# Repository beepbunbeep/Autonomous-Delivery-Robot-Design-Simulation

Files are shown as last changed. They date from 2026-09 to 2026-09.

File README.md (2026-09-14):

Hello!
Added here are all the files related to my autonomous delivery robot project. I designed the full robot architecture in SolidWorks after calculating needed strength under the planned load with a safety factor of 1,5.
Then, I developed MATLAB/Simulink models for kinematic and dynamic analysis, trajectory tracking and control-system evaluation. I dimensioned each of the three motors under simulated load and overload conditions and selected appropriate models. 

The design is fully functional, all is calculated and tested in MATLAB/SIMULINK Multibody.

The battery, driving, steering and drawer actuation motors have all be dimensioned and selected. These can be found in the provided documentation.

The documentation is currently only in Macedonian, as I made this for one of my classes however I will work on providing an English version for wider accessibility. 

I am making these publicly available because I value such repositories when I find them, and it is my great honor to be able to contribute to the engineering community. 
However I humbly ask that you do not use these to cheat on your own classes or pass this project off as your own.

I am not affiliated in any way with the Snoopy brand and have only used Snoopy's likeness to make this project more visually compelling (cuter). No profit has been or will be generated. 

***KEEP IN MIND THAT THERE MAY BE SOME INCONSISTENCIES BETWEEN THE PROJECT FILES AND DOCUMENTATION BECAUSE OF A MISHAP WITH THE VERSION SAVES. THE MAIN PARTS ARE GOOD BUT DETAILS NEED TO BE IRONED OUT.***

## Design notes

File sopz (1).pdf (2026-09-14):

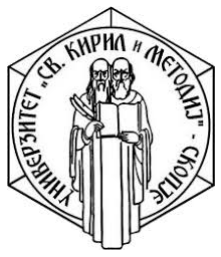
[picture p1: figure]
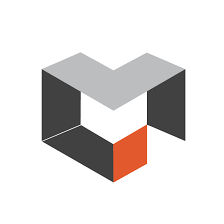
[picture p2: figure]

Универзитет Св. Кирил и Методиj Машински Факултет Скопjе

Семинарска задача по предметот: Механика на роботи

# Дизаjн и симулациjа на АУВ робот за достава

Изработено од: Аника Абдулаху 3132

Ментори: Доц. д-р. Маjа Аначкова Доц. д-р. Деjан Шишковски

## Содржина

1 Вовед | 2
2 Барања на роботот | 3
3 Модел во SolidWorks | 4
4 Сензори и актуатори | 5
5 Симулациjа | 10
6 Заклучок | 15

Абстракт
Во овоj проект е развиен и верификуван концепт на автономен доставен робот AGV со автоматски отварачки товарен отсек и приjатен дизаjн. Механичкиот модел е изработен во SolidWorks, вклучуваj´ки шасиjа, погонски систем и механизам за отворање на отсекот, при што се земени предвид производствени и монтажни ограничувања. Моделот е интегриран во Simulink за спроведување на кинематичка и динамичка анализа, планирање на траекториjа и развоj на контролни алгоритми за прецизно следење и безбедно ослободување на товарот. Симулациите ги оценуваат перформансите во различни работни сценариjа, вклучуваj´ки вариjации на оптоварување, нарушувања и ограничувања на актуаторите. Резултатите покажуваат дека предложениот дизаjн и контролна стратегиjа обезбедуваат стабилно и прецизно следење на траекториjата, сигурно функционирање на механизмот за отворање и добра прифатливост за корисникот во урбани средини. Проектот jа демонстрира ефикасната интеграциjа на CAD дизаjнот и системската симулациjа како основа за понатамошна оптимизациjа и експериментална реализациjа.

## 1 Вовед

Во овоj проект е дизаjниран и симулиран автономен доставен робот со товарен отсек коj автоматски се отвора и со внимателно осмислен естетски дизаjн. Процесот започна со прецизно тридимензионално моделирање во SolidWorks, каде што беа дефинирани конструктивните елементи, споjките и механичките ограничувања на шасиjата, погонскиот систем и механизмот за отворање на отсекот. Моделот потоа беше интегриран во Simulink за да се извршат детални кинематички и динамички анализи, со цел да се проценат положбите, брзините, забрзувањата, како и силите и моментите кои влиjаат на перформансите.
Проектот има за цел да демонстрира методолошка интеграциjа поме´гу CAD дизаjнот и системската симулациjа. Во Simulink беа спроведени студии на траекториjа и модели на динамика за да се верификуваат теоретските предвидувања и да се идентификуваат критичните параметри за стабилност и прецизност. За контролата беа развиени и тестиранe регулатори и "feedforward"стратегии за следење на зададените траектории, при што се анализираше временскиот одговор, грешката при следење и отпорноста на нарушувања. Резултатите обезбедуваат солидна основа за понатамошна оптимизациjа и експериментална валидациjа.
Практичниот фокус на проектот е да се добие инженерски изводлив и оперативен AGV коj може да се пренесе од виртуелна симулациjа во прототип. Во SolidWorks дизаjнот е оптимизиран за монтажа и производствени ограничувања, додека во Simulink се симулираа реални работни сценариjа: различни патеки, оптоварувања, нарушувања и ограничувања на актуаторите. Механизмот за автоматско отворање на товарниот отсек е дизаjниран и контролно интегриран така што обезбедува безбедно и прецизно ослободување на товарот, а естетскиот дизаjн jа подобрува прифатливоста за корисникот во урбани средини.
Комбинациjата на SolidWorks за прецизен механички дизаjн и Simulink за кинематичка, динамичка и контролна симулациjа овозможи целосен инженерски работен тек од концепт до верификациjа. Овоj пристап значително jа намалува неизвесноста пред изработка на физички прототип и дава конкретни препораки за материjали, димензии на погонските елементи и параметри на контролата, како и следни чекори за тестирање и индустриска имплементациjа.

## 2 Барања на роботот

За успешна реализациjа на проектот за автономен доставен робот AGV со автоматски отварачки товарен отсек беа дефинирани следниве барања, класифицирани на механички, функционални, симулациски и ергономски барања.

Механички δарања:

- Робустна и компактна шасиjа, оптимизирана за урбани средини, коjа одговара на формата на пове´ке разни предмети.
- Механизам за автоматско отворање и затворање на товарниот отсек, со сигурно и прецизно функционирање.
- Лесна конструкциjа за намалување на потрошувачката на енергиjа.
- Оптимизациjа на материjали и димензии за практична изработка.

Функционални δарања:

- Решавање на проблемот на „последните три метри“: роботот мора да може да доставува директно до врата на потрошувачите, без потреба трговците да излегуваат надвор или да одат тротуар подолу. [1]
- Автономно движење по зададени траектории со висока прецизност.
- Систем за избегнување пречки и адаптациjа на патеката.
- Контролна логика за управување со траекториjа, брзина и стабилност.
- Функционирање во тристрана пазарна динамика: трговци кои бараат брза и сигурна предавање на производи, потрошувачи со различни преференции за начинот на достава, роботот како посредник коj ги поврзува двете страни.

Симулациски δарања:

- Кинематичка анализа за проверка на положби, брзини и ограничувања.
- Динамичка анализа за проценка на сили, моменти и инерциjални ефекти.
- Тестирање на контролни алгоритми во различни сценариjа (оптоварувања, нарушувања).

Есшешски и ерıономски δарања:

- Дизаjн коj е визуелно привлечен и приjателски за корисниците.
- Ергономски пристап за лесна интеракциjа при товарење и растоварување.
- Визуелно впечатлив дизаjн коj го прави роботот лесно препознатлив за други учесници во сообра´каjот.
- Рабовите на роботот треба да бидат мазни, цврсти и заоблени за да се минимизира можноста за повреда доколку доjде до судир. [2]

## 3 Модел во SolidWorks

3D моделот на роботот „Snoopybot“ е изработен во SolidWorks, коj овозможува прецизно моделирање, склопување и анализа на механички конструкции и притоа дозволува импортирање на моделот во MATLAB Simulink за негова симулациjа и анализа. Со користење на CAD алатките во SolidWorks беше изработен целосен модел на роботот, вклучуваj´ки jа шасиjата, тркалата, просторот за достава, декоративните елементи и механизмот за автоматско отворање.

При моделирањето беа дефинирани главните димензии на конструкциjата, при што вкупната должина на роботот изнесува 700 mm, ширината 550 mm, а висината 678.81 mm. Централниот дел од конструкциjата е наменет за транспорт на пратки и е димензиониран така што овозможува доволен простор за сместување на помали предмети. Дополнително, во моделот се вклучени и тркалата со радиус R75 mm, кои обезбедуваат стабилност и подвижност на роботот.

Во SolidWorks беше изработен и склопот (assembly) на сите компоненти (Слика 1 и 2), со што се овозможи проверка на нивната ме´гусебна положба и функционалност. Со користење на пресечни прикази (Section A-A и Section B-B) беше анализирана внатрешната структура на роботот и распоредот на механичките елементи. Овие пресеци овозможуваат подобар увид во конструкциjата и начинот на интеграциjа на механизмот за автоматско отворање.

Дополнително, SolidWorks овозможи изработка на техничка документациjа и работилнички цртежи со потребните димензии, пресечни прикази и ортогонални проекции. На овоj начин беше добиен детален инженерски приказ на роботот, коj може да се користи за понатамошна изработка, анализа и симулациjа на системот.

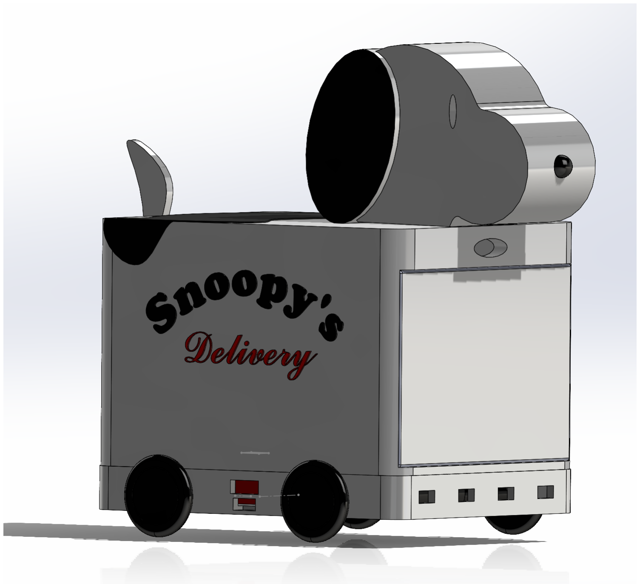
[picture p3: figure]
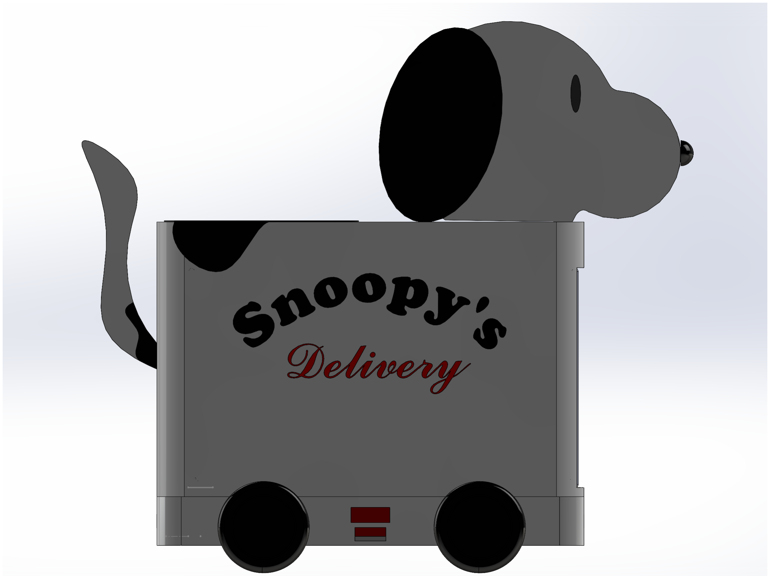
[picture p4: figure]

Слика 1: Диметричен поглед | Слика 2: Лев поглед на роботот

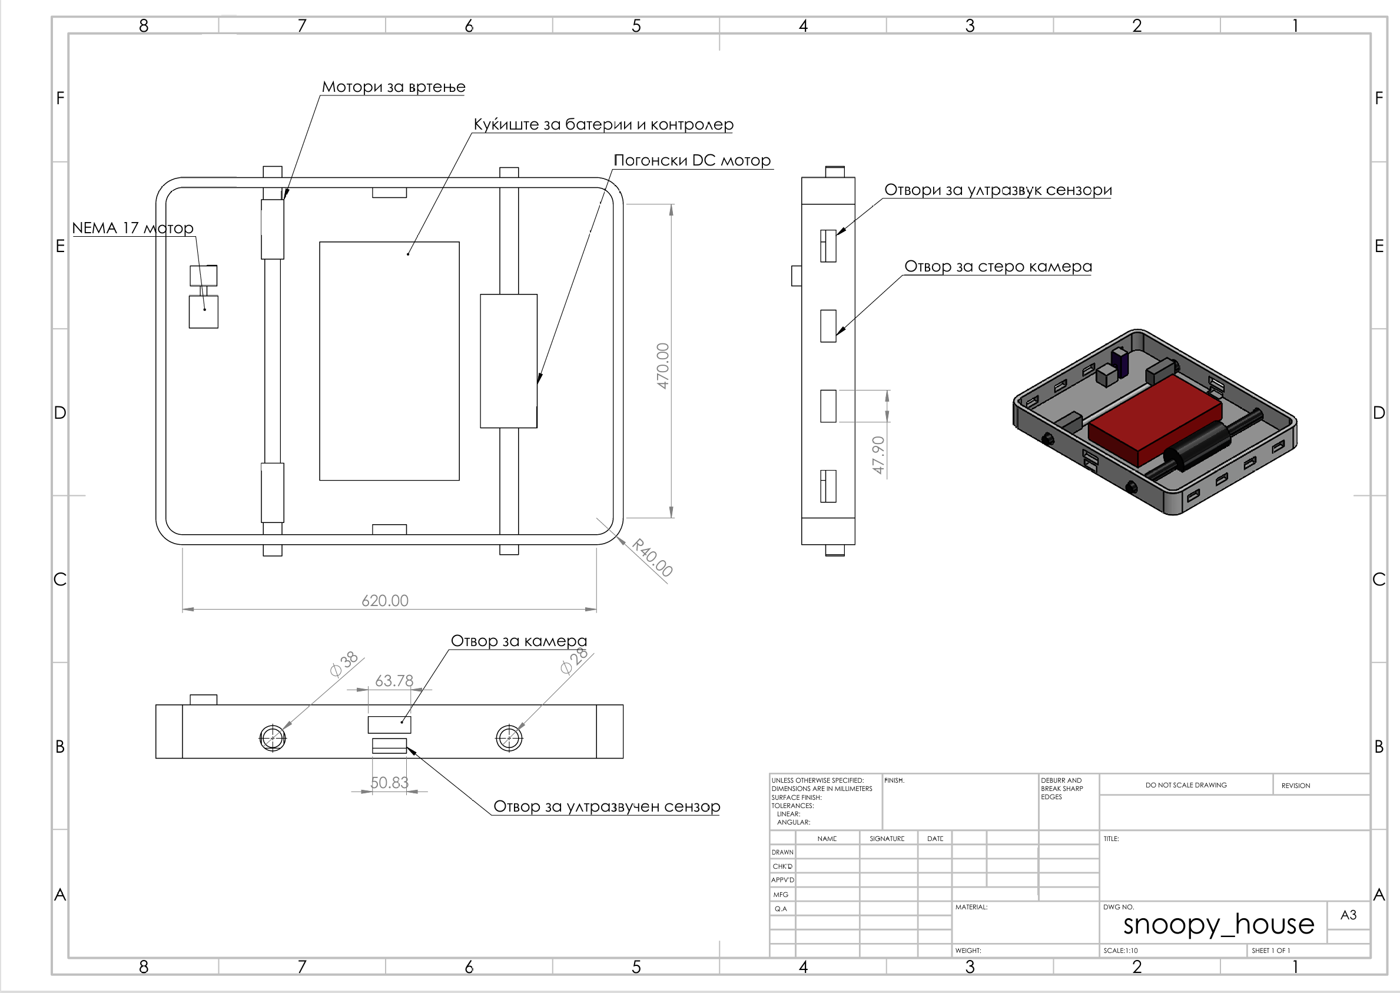
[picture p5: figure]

Слика 3: Долен дел - ку´киште за мотори, сензори, батерии и контролер.

## 4 Сензори и актуатори

За упешно функционирање на роботот и следење на околината, искористени се низа сензори и актуатори, поставени низ целата шасиjа. Сензорите овозможуваат 360deg визуелна покриеност на околината околу роботот. Околу периметарот на долната плоча се поставени по три ултразвучни сензори од предната и задната страна, кои служат за детектирање на стаклени и рефлективни површини, како и детектирање на ниски препреки на патот (Слика 3). На средина на секоjа страна е поставена стерео камера коjа служи за проценка на висината на тротоарите и за препознавање на дупки и други нерамнини на патот. Стерео камерата е уред со два или пове´ке ле´ки и сензори за слика што симулира човечки бинокуларен вид. Со снимање на една сцена од пове´ке гледни точки, системот jа пресметува длабочината и конструира 3D слики користеj´ки математички метод наречен триангулациjа. Исто така, за препознавање на удари и колизии користени се два IMU сензори.

На предната и задната страна на роботот како и на двете бочни страни се поставени камери за машинска визиjа. Тие служат за да формираат jасна слика на околината и овозможуваат целосна покриеност на просторот околу роботот. Исто така на предната страна е поставен LiDar сензор коj прецизно jа мапира околината и пресеметува растоjаниjа. Тоj користи пулсирачки ласерски зраци и го мери времето кое и е потребно на светлината да се рефлекитра од обjектите во околината и врати до сензорот. LiDar сензорите генерираат високо-прецизни 3-Д координаати, наречени точковни облаци.

Со интегрирање на пове´ке сензори се добива целосна покриеност на просторот околу роботот и технолошки вишок коj обезбедува сигурност и безбедност при работа.

Роботот користи комбинациjа од различни актуатори зависно од подсистемот. Главниот погонски систем е реализиран со DC редуктивен мотор коj обезбедува континуирано ротационо движење за движење напред и назад. Системот за управување (свртување) користи сервомотори со висок вртежен момент, кои овозможуваат прецизно аголно позиционирање на предната оска и имплементациjа на Ackermann-тип управување. Доставниот оддел (багажникот) е управуван со степер мотор, коj jа претвора ротациjата во контролирано линеарно движење преку механизам со запчаник и решетка или навоjна шипка. Оваа комбинациjа на актуатори овозможува модуларен дизаjн каде што секоj подсистем користи наjсоодветен тип на управување со движење, со што се постигнуваат прецизност и сигурност во работата.

### 4.1 Механизам за автоматско отварање

За овозможување на автоматизирана достава, каj роботот „Snoopybot“ е имплементиран механизам за автоматско отворање на преградата за достава. Механизмот е поставен на задниот дел од роботот и овозможува контролирано отворање и затворање на вратата со цел безбедно оставање или преземање на пратката.

Како што е прикажано на техничкиот цртеж, вкупната должина на роботот изнесува 700 mm (Секциjа B-B), додека ширината на предниот дел е 470 mm. Просторот за складирање е сместен во централниот дел на конструкциjата и е димензиониран така што овозможува транспорт на помали пакети и предмети. Висината на роботот до горниот декоративен елемент изнесува 678.81 mm, што придонесува за компактна и стабилна конструкциjа.

Механизмот за отворање е конципиран како лизгачки систем, при што фиоката се придвижува линеарно со помош на електричен погон. Ваквиот тип механизам е избран поради неговата едноставност, сигурност и можност за лесна интеграциjа со електронскиот систем за контрола. Дополнително, лизгачкиот механизам зафа´ка мал простор и не влиjае врз стабилноста на роботот при движење. Фиоката може да носи товар до приближно 10kg. Погонскиот мотор е димензиониран со фактор на безбедност 1.5, што значи пред да настане разор максималната носивост е 15kg.

### 4.2 Технички параметри и избор на погон

При изборот на погонскиот систем беа земени предвид димензиите на роботот, неговата маса, како и потребната носивост. Роботот е дизаjниран со компактни димензии од приближно 700 mm должина, 550 mm ширина и 678.81 mm висина (Слика 4), што овозможува лесно маневрирање во затворени и урбани средини.

За придвижување на механизмот за автоматско отворање е предвиден електричен DC мотор со редуктор, коj обезбедува доволен вртежен момент при мала брзина. Употребата на редуктор овозможува попрецизна контрола на движењето и помало оптоварување на моторот. Линеарното движење на вратата е реализирано преку водилки и преносен механизам, со што се обезбедува стабилно и мазно отворање.

Тркалата на роботот се поставени симетрично во долниот дел од конструкциjата, при што радиусот на тркалата изнесува R75 mm. Оваа конфигурациjа овозможува стабилно движење и рамномерна распределба на тежината. Конструкциjата е изработена така што центарот на маса останува низок, со што се подобрува стабилноста при движење и при отворање на преградата.

Напоjувањето на системот е предвидено преку батериски пакет, коj обезбедува автономна работа на роботот и на погонските механизми. Контролата на моторите и механизмот за отворање се реализира преку микроконтролер, коj овозможува автоматизациjа и можност за далечинско управување.

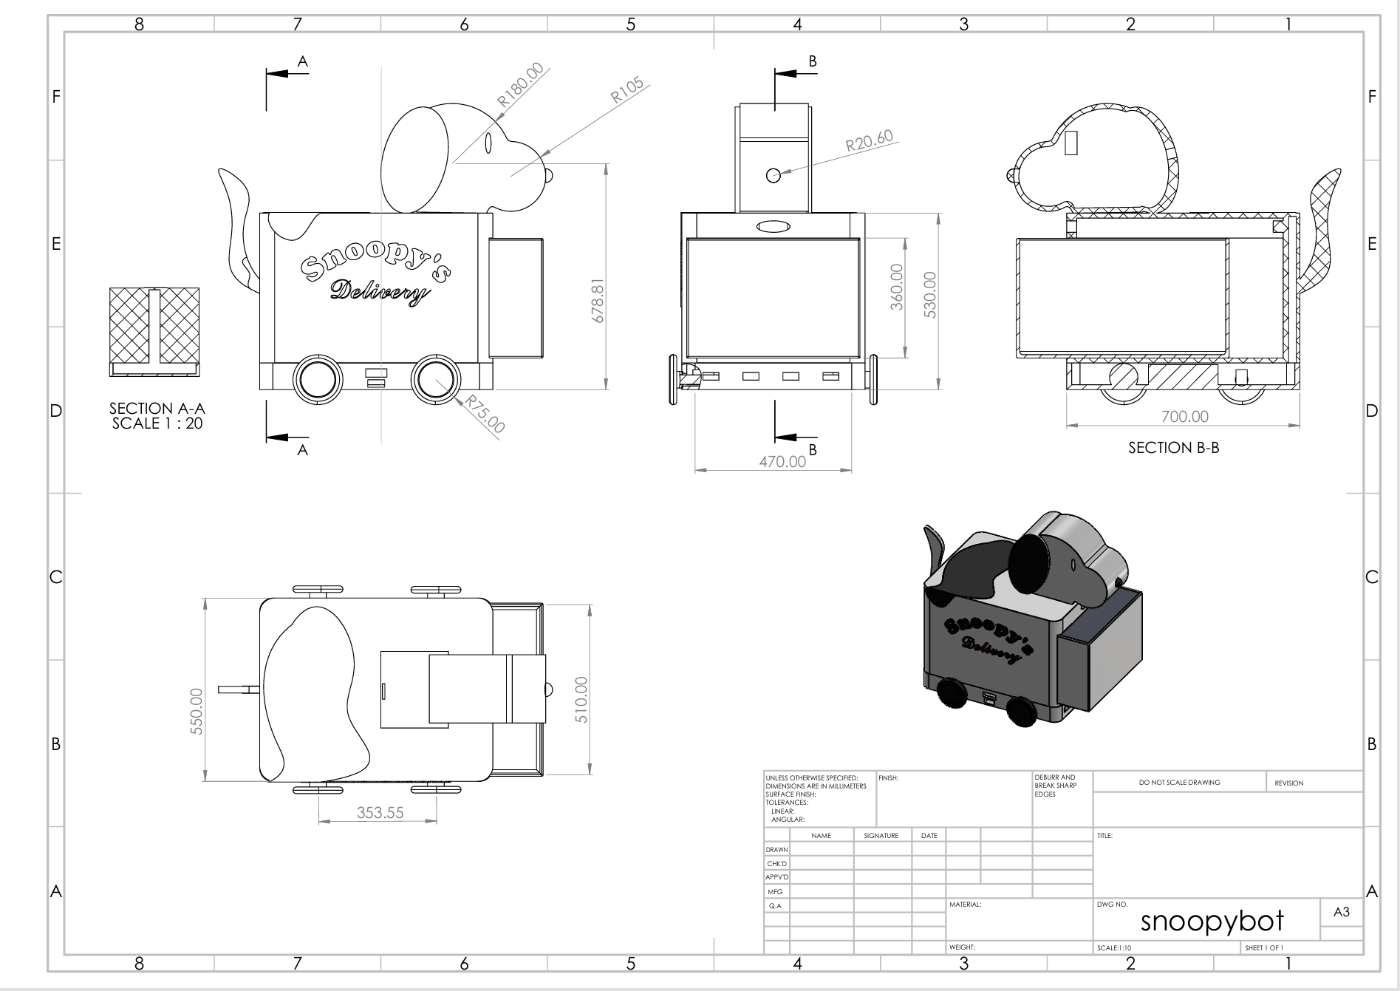
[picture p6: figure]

Слика 4: Технички цртеж на роботот

Дизаjнот на мобилниот робот користи тркала со радиус од 75 mm, што одговара на диjаметар од 0.15 m. Обемот на тркалото изнесува C = πD ≈ 0.471 m, што значи дека едно целосно вртење на тркалото го поместува роботот приближно 47.1 cm нанапред. Линеарната брзина на роботот е директно пропорционална со брзината на вртење на моторот и може да се изрази со v =

πD·RPM
60 . За типични вредности
на редуцирани DC мотори, брзина од 150–200 RPM дава реалистична крстосувачка брзина од околу 1.18–1.57 m/s, додека повисоки брзини до 300 RPM резултираат со максимална брзина од приближно 2.36 m/s. Овие вредности се во согласност со мали автономни доставни роботи и претставуваат компромис поме´гу стабилност, контро-

лабилност и ефикасност.

### 4.2.1 Избрани мотори

Изборот на погонскиот мотор е направен врз основа на резултатите добиени од симулациjата на роботот при максимално оптоварување. Роботот користи еден мотор за погон на двете задни тркала. При симулациjата беше добиен вртежен момент од 24.47 N·m по тркало и аголна брзина од 12 rad/s. Вкупниот вртежен момент потребен за погонската оска изнесува 48.94 N·m. Потребната механичка мо´кност е пресметана според релациjата P = τω, при што е добиена вредност од 587.28 W. За да се обезбеди сигурна работа на системот во услови на динамички оптоварувања, триење, загуби во преносниот механизам и можни отстапувања од симулацискиот модел, беше применет фактор на сигурност од 1.5. Со тоа потребната проектирачка мо´кност изнесува 880.92 W. Врз основа на овие резултати е избран DC мотор со редуктор со номинална мо´кност од 1000 W, коj обезбедува доволна резерва на мо´кност и вртежен момент за сигурно движење на роботот во сите предвидени работни услови.

Избран е MY1020 1000W со четкици, кои работи на напон 36V. За да се обезбеди потребниот вртежен момент на погонските тркала, поме´гу моторот и погонската оска е применет редукциски пренос. Избраниот мотор има номинален вртежен мо-

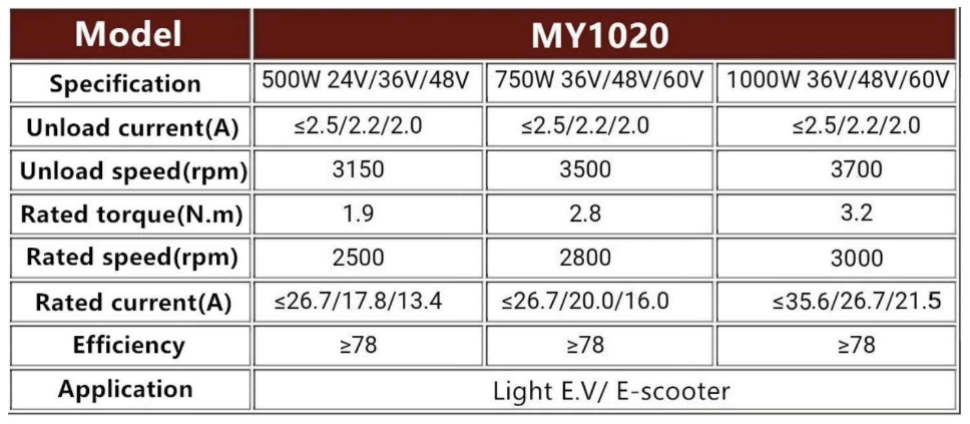
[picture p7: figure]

Слика 5: Спецификации на моторот MY1020

мент од 3.2 N·m при брзина од 3000 rpm, што не е доволно за директен погон на роботот. Поради тоа е предвиден преносен однос од приближно 15:1, со што брзината на ротациjа се намалува, а вртежниот момент пропорционално се зголемува. На овоj начин се овозможува добивање на потребниот вртежен момент за придвижување на роботот при максимално оптоварување, додека истовремено се задржува доволна резерва на мо´кност за сигурна и стабилна работа на системот.

За управување на предните тркала е избран серво моторот DS3218. Изборот на овоj мотор се должи на неговата способност за прецизно аголно позиционирање, што е од особена важност за системите за управување каj мобилни роботи. DS3218 обезбедува висок вртежен момент во компактни димензии, овозможуваj´ки сигурно завртување на тркалата дури и при присуство на оптоварувања и отпори кои се jавуваат при движењето на роботот. Дополнително, серво моторот располага со вградена повратна врска за позициjата, што овозможува точно следење на зададениот агол без потреба од дополнителни сензори или сложени контролни алгоритми. Благодарение на неговата едноставна интеграциjа, сигурност и прецизност, DS3218 претставува соодветно решение за управувачкиот механизам на доставниот робот.

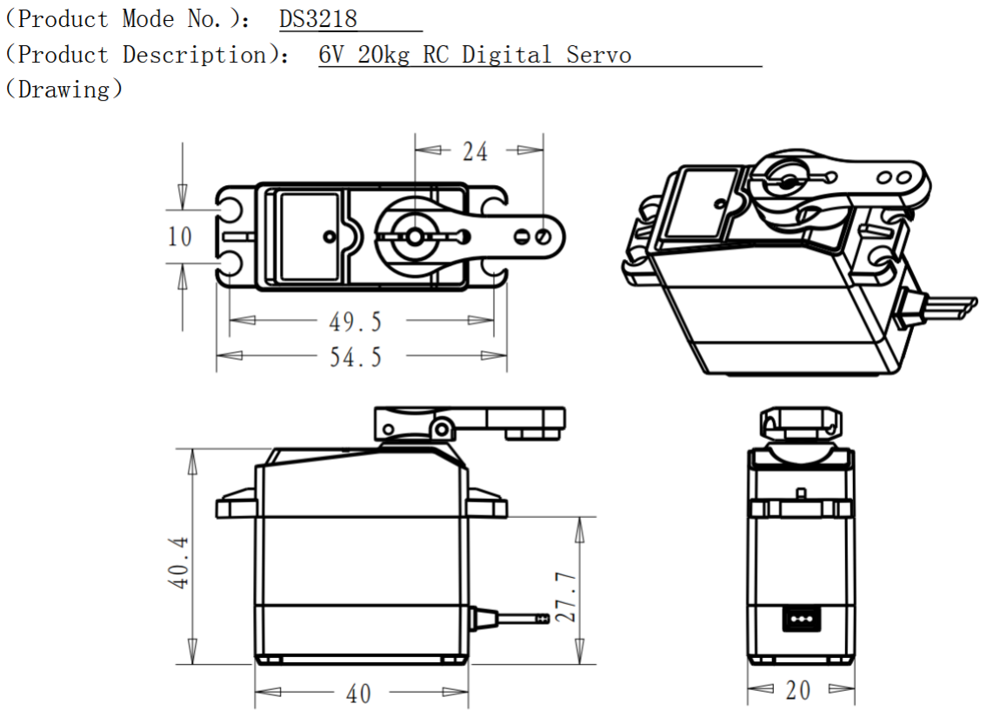
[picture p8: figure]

Слика 6: Димензии на DS3218 мотор

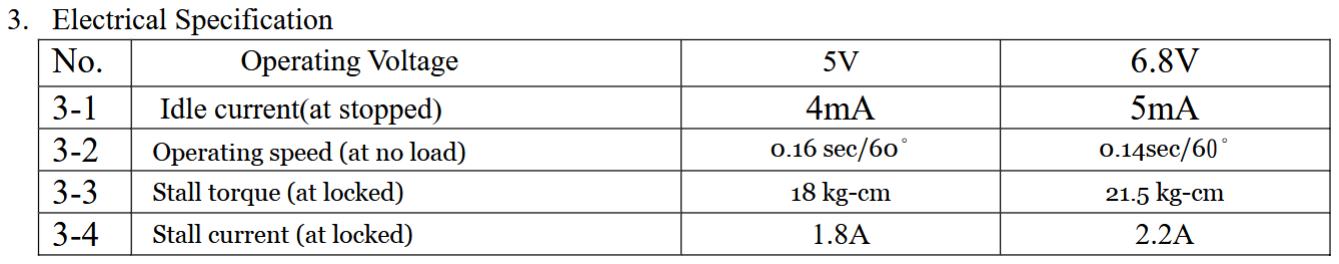
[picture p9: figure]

Слика 7: Електрични спецификации

За придвижување на механизмот на фиоката е избран NEMA 17 степер мотор. Изборот на овоj мотор се базира на неговата способност за прецизно позиционирање и контролирано движење без потреба од сложени системи за повратна врска. Благодарение на дискретното чекорно движење, степер моторот овозможува точно извлекување и вовлекување на фиоката, при што позициjата може лесно да се контролира преку броjот на извршени чекори. Дополнително, NEMA 17 обезбедува доволен вртежен момент за совладување на оптоварувањата кои се jавуваат при движењето на фиоката и транспортирањето на товарот. Неговата сигурност, едноставна контрола и висока точност го прават соодветен избор за автоматизираниот механизам на доставниот робот.

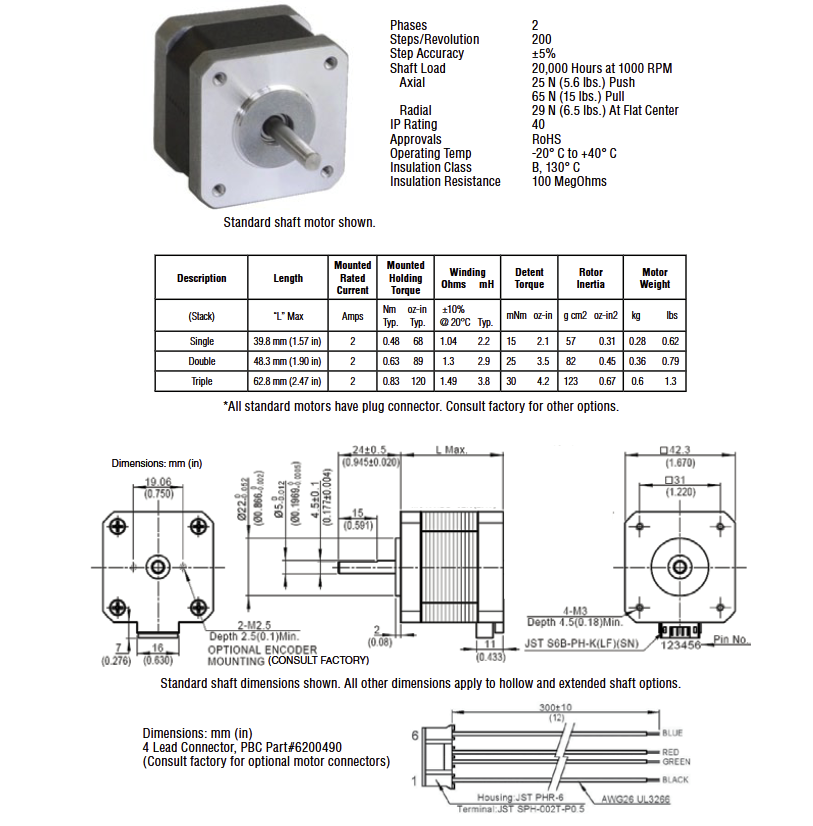
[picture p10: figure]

Слика 8: Спецификации на моторот за управување NEMA 17

## 5 Симулациjа

Во овоj проект е извршен "top down"начин на проектирање на робот, со тоа што дефинирани се целните параметри кои изведеното решение треба да ги достигне, направена е симулациjа со цел да се вчита моментот коj го бара роботот, и според тоа е направен избор на мотор. Симулацискиот модел ги опфа´ка главните подсистеми на платформата, вклучуваj´ки го погонскиот систем, механизмот за управување и механизмот на автоматско отварање на фиоката (Слика 4). Преку интеграциjа на CAD геометриjа и "multibody"динамика, се овозможува реалистична репрезентациjа на движењето и интеракциjата поме´гу компонентите.
Целта на симулациjата е да се направи избор на актуатори, да се направи кинематска анализа, и да се процени стабилноста и управливоста на системот при различни брзини и команди за движење. Дополнително, симулацискиот модел служи за проверка на правилното функционирање на механизмот за багаж, како и за идентификациjа на потенциjални проблеми во геометриските ограничувања и поврзувањето на зглобовите.

### 5.1 Кинематска и динамична анализа

Со помош на Simulink изгенерирани се следните графици, кои jа прикажуваат брзината и забрзувањето на системот (Слика 5 и 6). Со PID контролерот се постигнува релативно мазно забрзување и доволно точно достигнување и задржување на брзината.
Со поставување на сензори за момент, позициjа, брзина и забрзување на секоj зглоб, добиваме претстава на ефективноста на PID контролерот во управувањето на роботот. Подолу се дадени добиените графици за момент, позициjа, брзина и забрзување на тркалата (Слика 5, 6, 7 и 8).

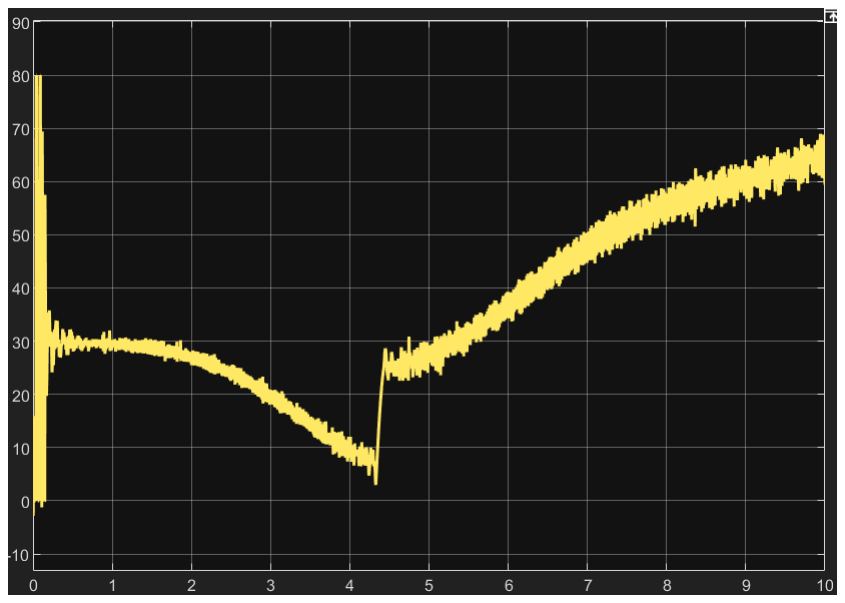
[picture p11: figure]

Слика 9: Момент на задните (погонски) тркала

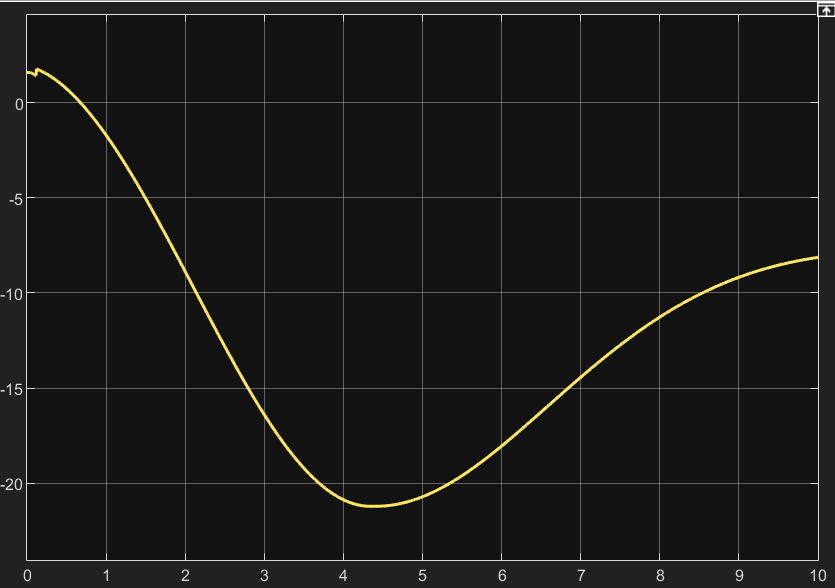
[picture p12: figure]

Слика 10: Позициjа на предните тркала

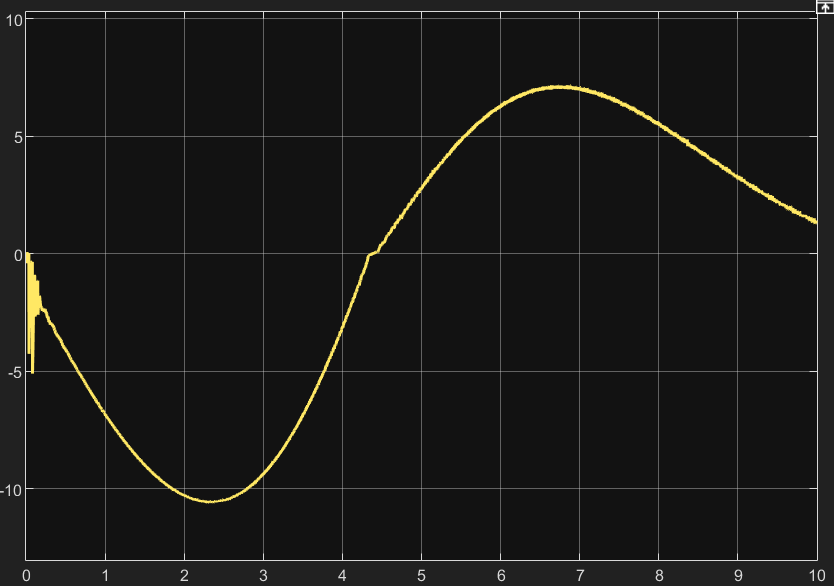
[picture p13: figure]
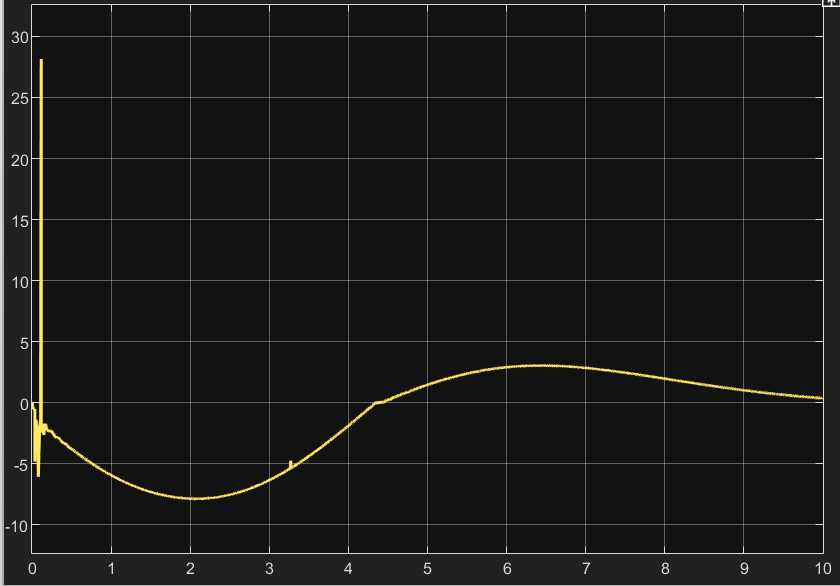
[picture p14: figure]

Слика 11: Брзина на роботот | Слика 12: Забрзување на роботот

### 5.2 Генерирање на траекториjа

Во оперативни услови траекториjата на роботот се генерира со помош на GPS за одредување на оптималниот пат, но во симулирани услови траекториjата се генерира директно преку управувачкиот сигнал. Со помош на блокот "Signal Editor"конструираме сигнал како на Слика 8.
Брзината на движење се контролира преку контрола на моментот (Слика 9). На почеток, роботот се движи напред со максимална брзина, коjа е околу 2m/s. Во третата секунда од симулациjата почнува свртувањето надесно, при што брзината на движење се намалува. По завршување на движењето, таа повторно се вра´ка на максимална. Преку оваа кратка секвенца се добива слика за одесувањето на роботот во реални сценариjа. Со менување на сигналните блокови може да симулираме разни траектории, со разни можни агли на свртување и радиуси на вртење на тркалата, согласно со Ackermann начинот на управување.

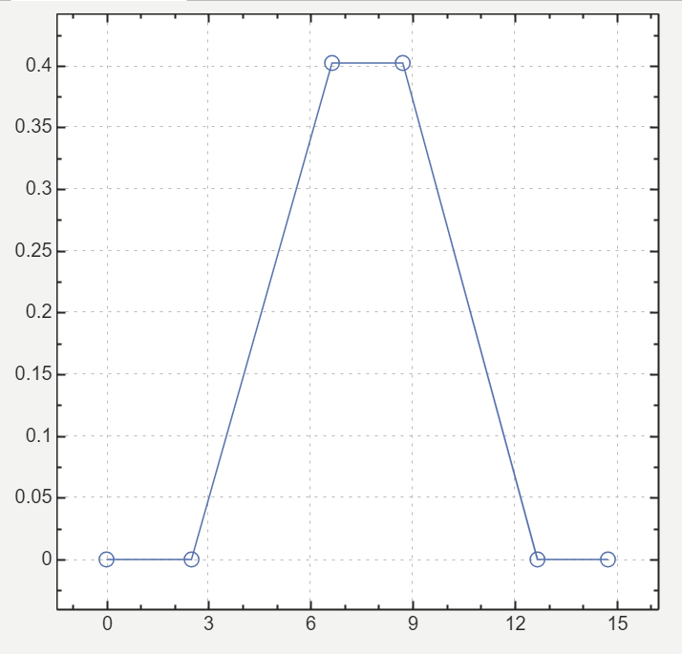
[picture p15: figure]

Слика 13: Сигнал за управување на предните тркала (контрола на траекториjата)

### 5.3 Контрола

Автономни доставни роботи имаат потреба од контрола, планирање на движењето, робустна локализациjа и планирање на рутата за да функционираат [3]. За симулациjа на контроланата архитектура користени се три PID контролери. Вредностите на P, I и D компонентите се одредени по експериментална постапка.

Резултатите од симулациjата покажуваат дека правилниот избор на кинематичка структура и актуатори е клучен за стабилно и реалистично однесување на системот. Исто така, симулациjата помогна да се идентификуваат и коригираат проблеми поврзани со ограничувања во зглобовите и поставувањето на движењата, со што се подобри вкупната функционалност на моделот.

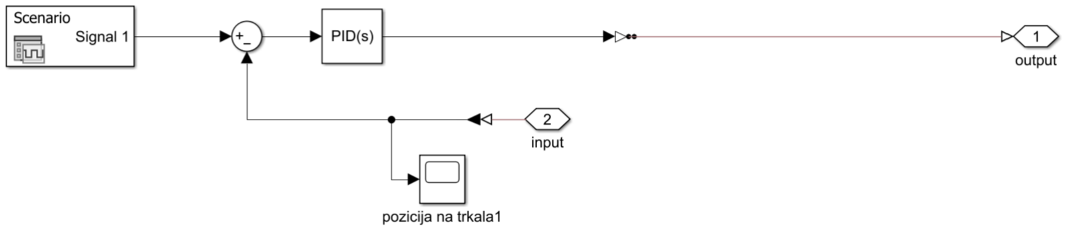
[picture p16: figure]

Слика 14: Контролна структура на управувачките мотори

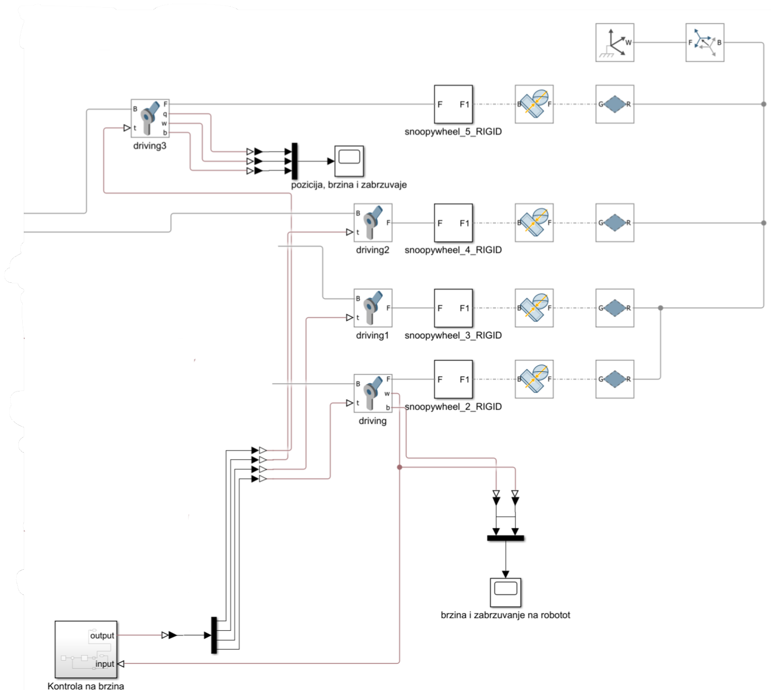
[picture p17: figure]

Слика 15: Погонување на тркалата

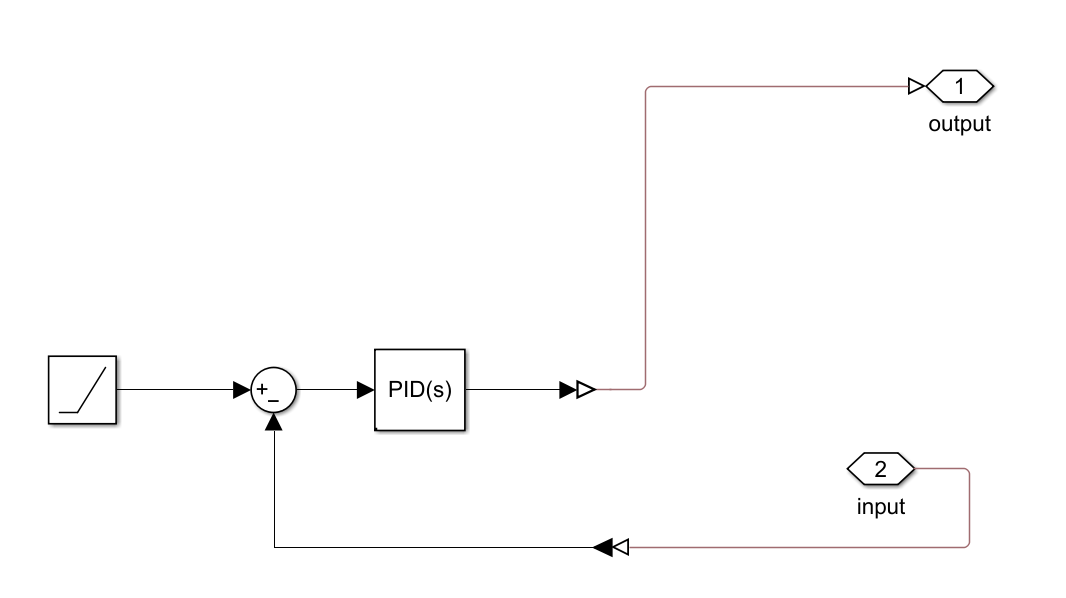
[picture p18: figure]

Слика 16: Контролна структура за погон

Во оваа секциjа беше извршена симулациjа на автономниот доставен робот со цел да се провери неговото кинематичко и динамичко однесување пред физичка изработка. Симулациjата овозможи анализа на движењето на платформата, функционирањето на управувачкиот систем и работата на механизмот за фиока во контролирана виртуелна средина.

## 6 Заклучок

Во овоj проект беше развиен и анализиран модел на автономен доставен робот, со фокус на неговата механичка конструкциjа, избор на актуатори и симулациска верификациjа. Главната цел беше да се дизаjнира функционална платформа способна за автономно движење, управување и испорака на обjекти преку интегриран систем коj комбинира погон, управување и механизам за товар.
Во фазата на дизаjн беа дефинирани клучните подсистеми на роботот, вклучуваj´ки го погонскиот систем со DC редуцирани мотори, управувачкиот механизам базиран на серво мотори и системот за фиока коj користи степер мотор за контролирано линеарно движење. Овоj избор на актуатори овозможува баланс поме´гу едноставност, прецизност и практична имплементациjа во реален систем. Понатаму, беше изработен симулациски модел во средина за мултибодиска динамика со цел да се провери однесувањето на роботот во контролирани услови. Симулациjата овозможи анализа на кинематиката, стабилноста при движење и правилното функционирање на механичките врски и зглобови. Во текот на овоj процес беа идентификувани и одредени ограничувања и проблеми во поставувањето на степените на слобода, што придонесе за подобро разбирање на моделот и неговата подобрена конфигурациjа.
Севкупно, проектот успешно демонстрира основен дизаjн и симулациjа на автономен доставен робот. Резултатите покажуваат дека избраната архитектура е изводлива и може да се имплементира во физички прототип со понатамошни оптимизации во областа на контрола, механичка стабилност и енергетска ефикасност. Овоj проект поставува основа за идни подобрувања, вклучуваj´ки интеграциjа на сензори, напредни алгоритми за навигациjа и подобрена автономиjа.

## Литература

[1] Stanley Tang and Ashu Rege. (2025, Sep.) Engineering autonomy for local commerce: Building dot and the autonomous delivery platform. DoorDash. Accessed: 2026-05-
14. [Online]. Available: https://careersatdoordash.com/blog/doordash-engineeringautonomy-for-local-commerce-dot-and-autonomous-delivery-platform/
[2] M. Hossain, “Autonomous delivery robots: A literature review,” IEEE Engineering Management Review, vol. 51, no. 4, pp. 77–89, 2023.
[3] D. Lee, G. Kang, B. Kim, and D. H. Shim, “Assistive delivery robot application for real-world postal services,” IEEE Access, vol. 9, pp. 141 981–141 998, 2021.

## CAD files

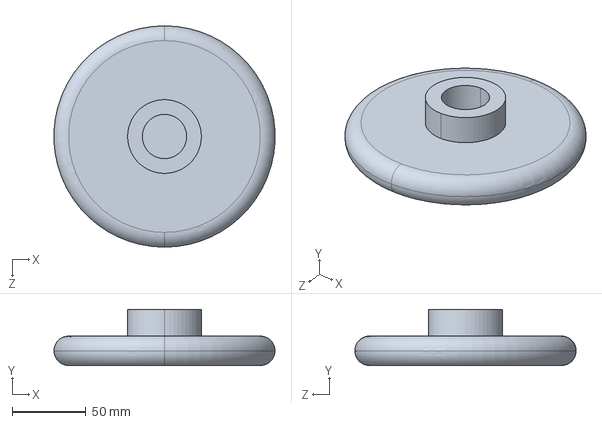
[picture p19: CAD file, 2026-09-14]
snoopy!wheel_Default_sldprt.STEP
149.8 x 38.0 x 150.0 mm

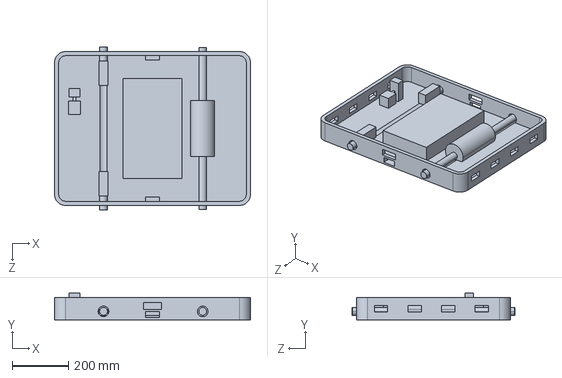
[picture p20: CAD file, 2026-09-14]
snoopy_house_Default_sldprt.STEP
700.0 x 95.0 x 583.7 mm

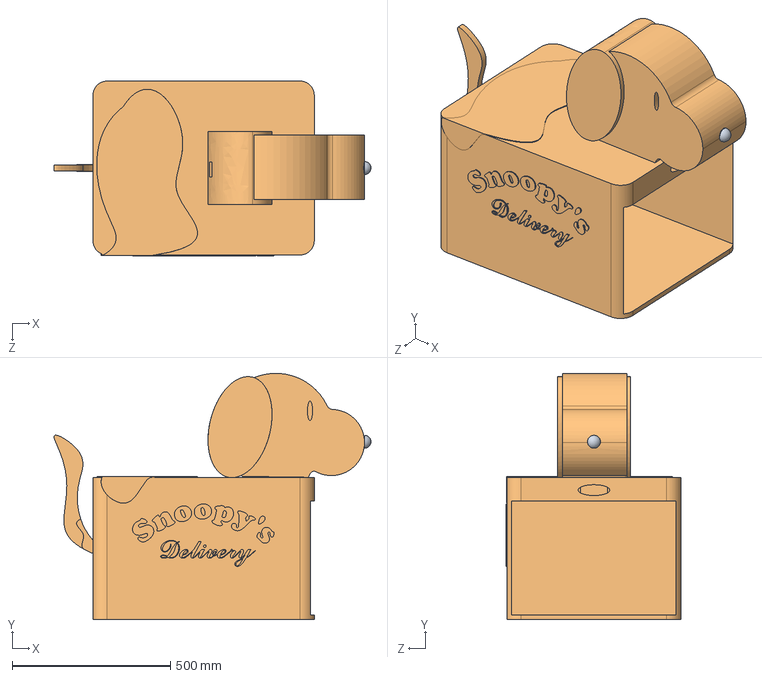
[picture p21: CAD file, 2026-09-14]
snoopy!_Default_sldprt.STEP
1002.3 x 778.7 x 553.0 mm

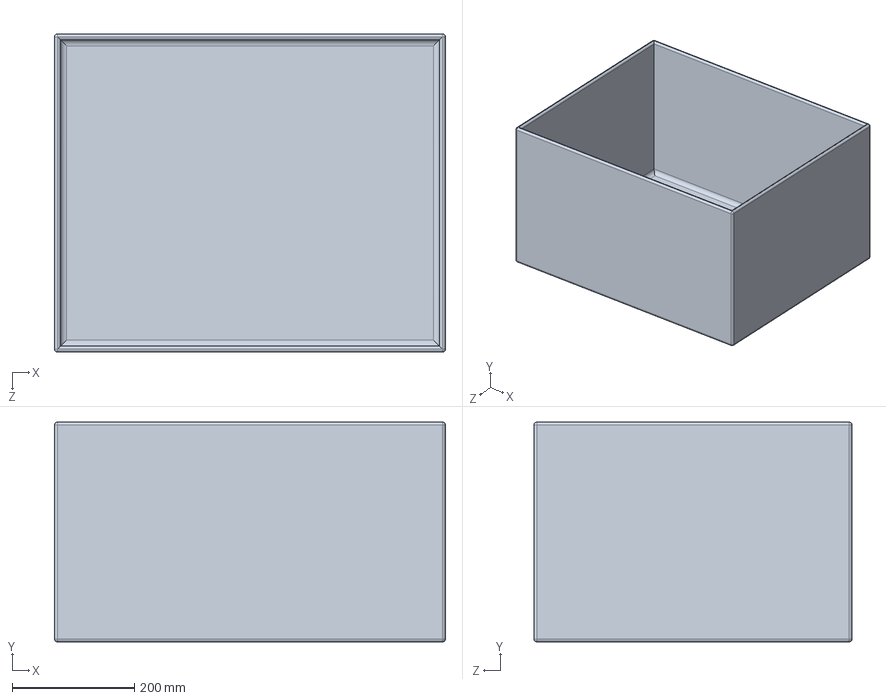
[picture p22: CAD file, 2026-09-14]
snoopy_drawer_Default_sldprt.STEP
638.5 x 359.0 x 520.0 mm

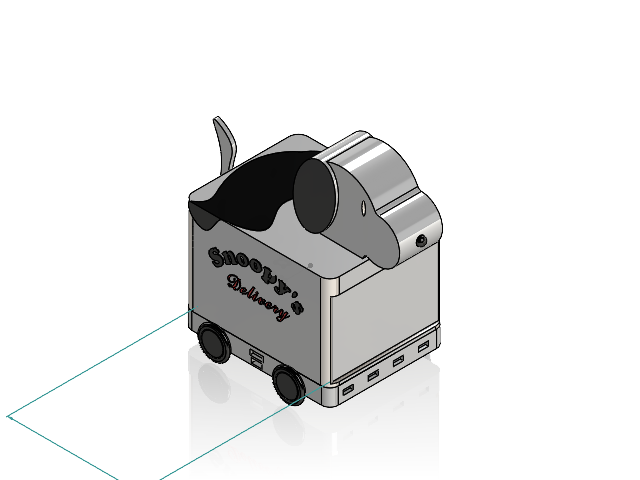
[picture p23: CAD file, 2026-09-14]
snoopybot.SLDASM
snoopy!
snoopy_house
snoopy_drawer
snoopy!wheel x 4

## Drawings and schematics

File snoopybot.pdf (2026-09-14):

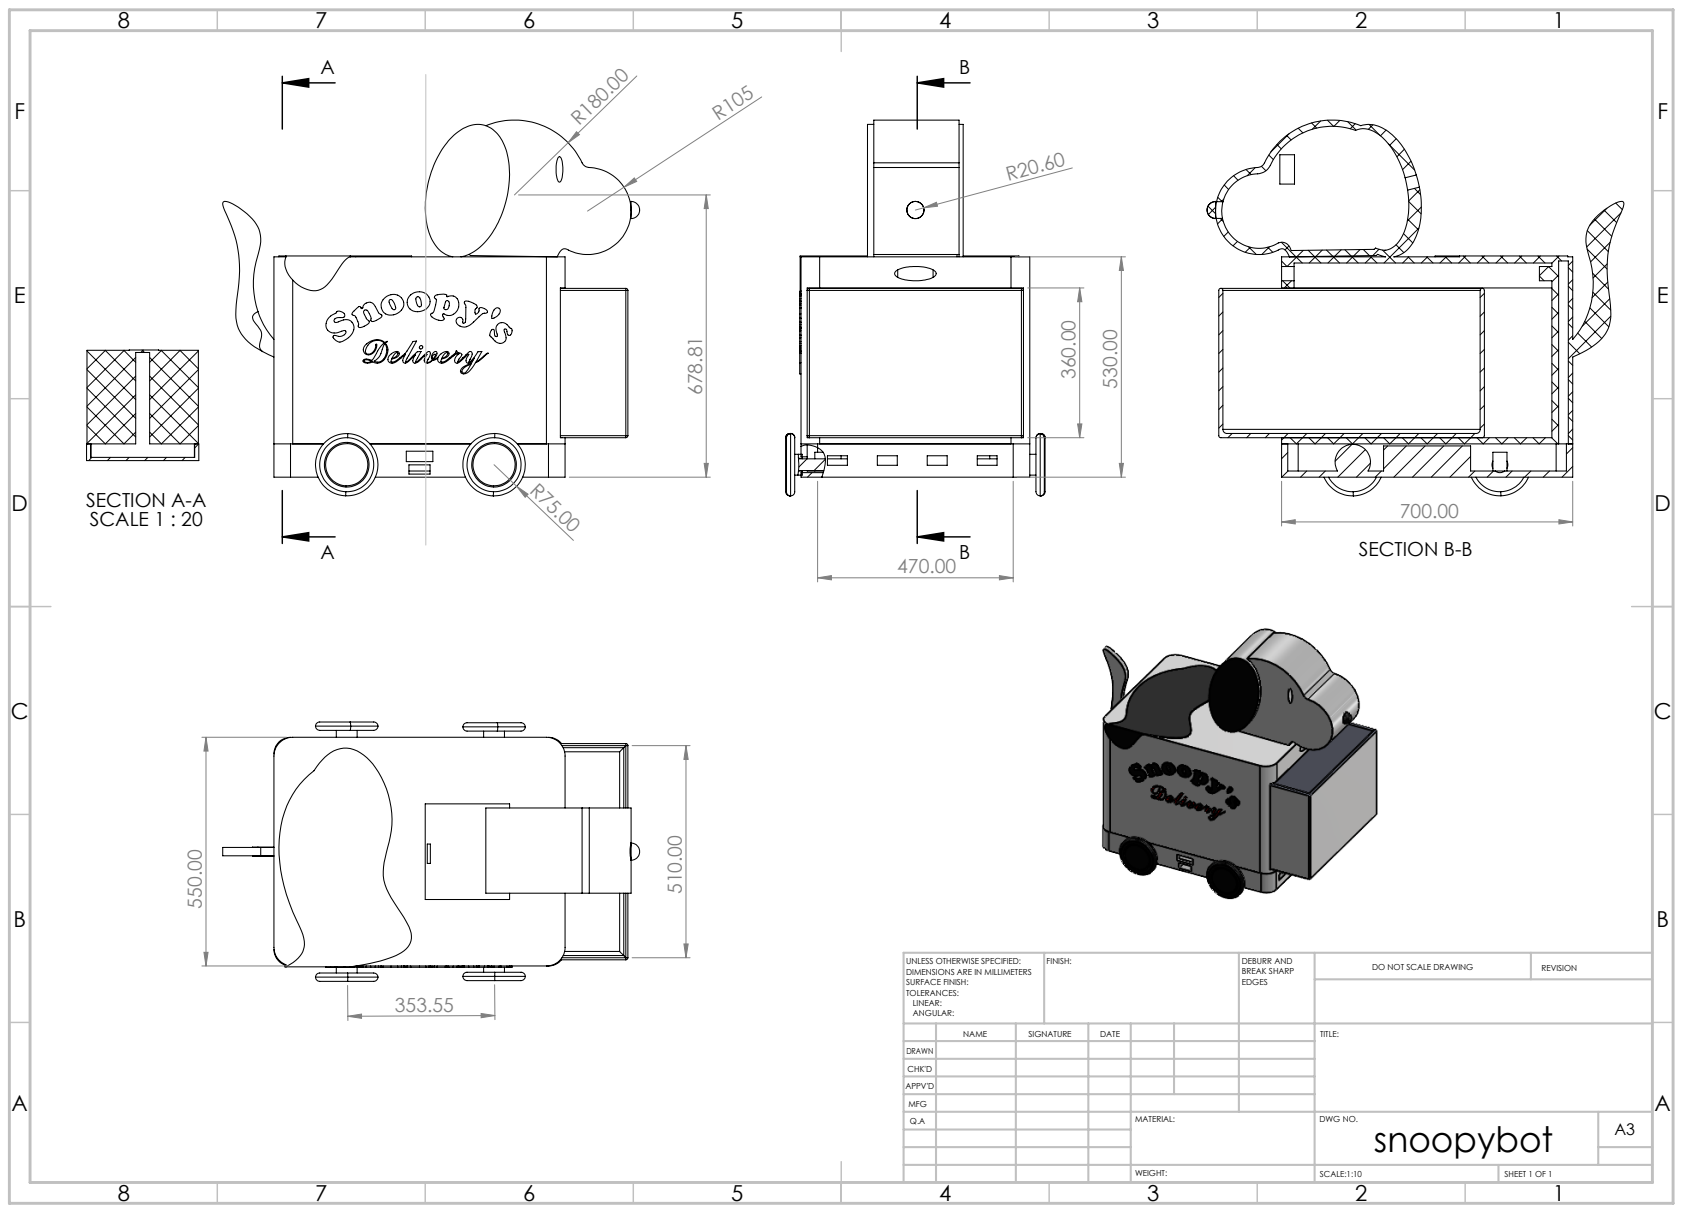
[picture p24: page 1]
SECTION A-A; SCALE 1 : 20; SECTION B-B; FINISH:; DEBURR AND; BREAK SHARP; DO NOT SCALE DRAWING; REVISION; SCALE:1:10; SHEET 1 OF 1

UNLESS OTHERWISE SPECIFIED:
DIMENSIONS ARE IN MILLIMETERS
SURFACE FINISH:
TOLERANCES:
LINEAR:
ANGULAR:

NAME | SIGNATURE | DATE | | | | TITLE:

DRAWN
CHK'D
APPV'D
MFG
Q.A | | | | MATERIAL: | DWG NO. snoopybot | A3

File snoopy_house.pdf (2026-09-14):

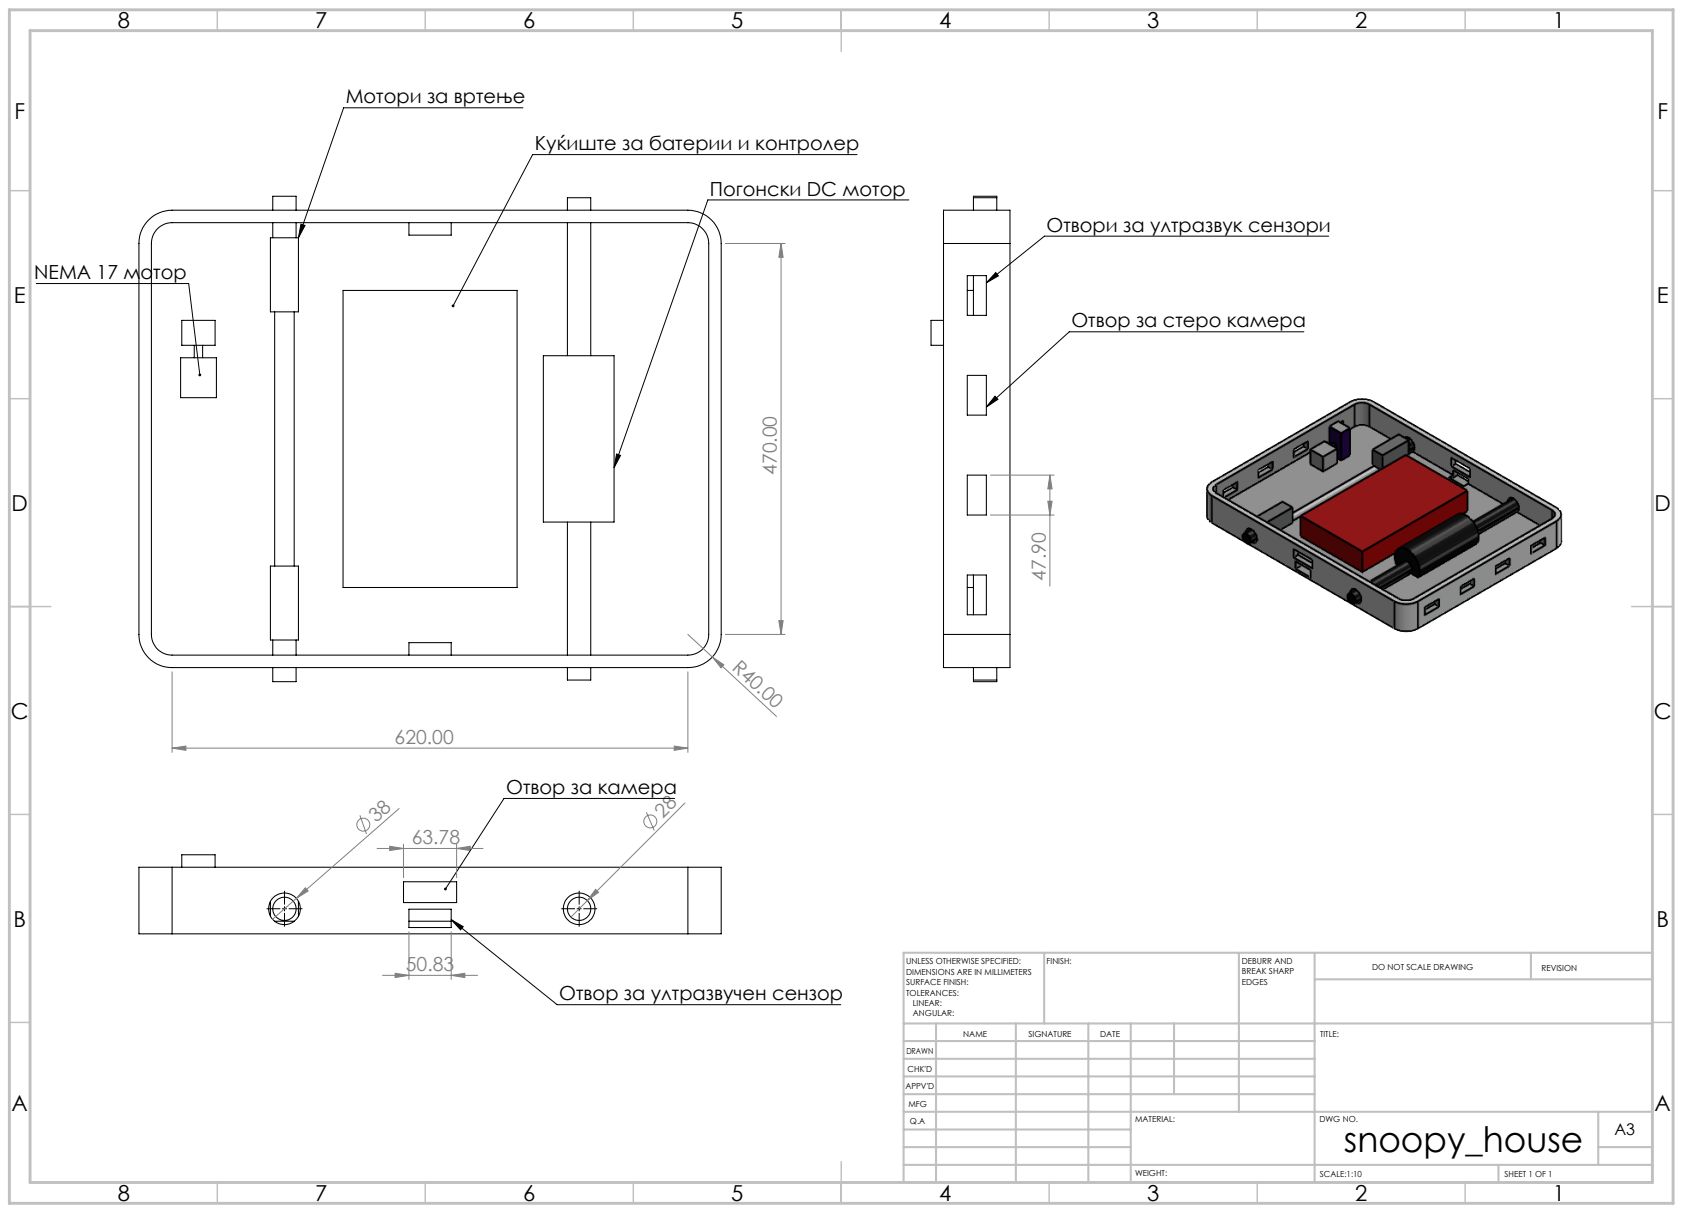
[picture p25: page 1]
NEMA 17 мотор; FINISH:; DEBURR AND; BREAK SHARP; DO NOT SCALE DRAWING; REVISION; SCALE:1:10; SHEET 1 OF 1

Мотори за вртење

Куќиште за батерии и контролер

Погонски DC мотор

Отвори за ултразвук сензори

Отвор за стеро камера

Отвор за камера

UNLESS OTHERWISE SPECIFIED:
DIMENSIONS ARE IN MILLIMETERS
SURFACE FINISH:
TOLERANCES:
LINEAR:
ANGULAR:

Отвор за ултразвучен сензор

NAME | SIGNATURE | DATE | | | | TITLE:

DRAWN
CHK'D
APPV'D
MFG
Q.A | | | | MATERIAL: | DWG NO. snoopy_house | A3

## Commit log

2026-09-14 Add files via upload
    Added STEP files referenced in SIMSCAPE model.
    [snoopy!_Default_sldprt.STEP, snoopy!wheel_Default_sldprt.STEP, snoopy_drawer_Default_sldprt.STEP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]
2026-09-14 Add files via upload
    PDF of Solidworks drawing of electronics and battery housing of the delivery robot.
2026-09-14 Added PDF of drawing of main robot chassis
    PDF of Solidworks drawing. Some of the dimensions may have been subject to change and hence are not final.
2026-09-14 Added assembly model
    [snoopybot.SLDASM]
